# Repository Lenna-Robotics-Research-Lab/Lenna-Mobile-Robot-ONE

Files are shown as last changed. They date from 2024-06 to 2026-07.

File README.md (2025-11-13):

<div align="justify">

# Lenna Mobile Robot ONE
Lenna Autonomous Mobile Robot is designed for educational and research purposes. It is built upon a robust hardware architecture that combines an ARM-based embedded microcontroller and a Jetson Nano single-board computer (SBC) to provide both low-level and high-level control capabilities.

<div align="center">

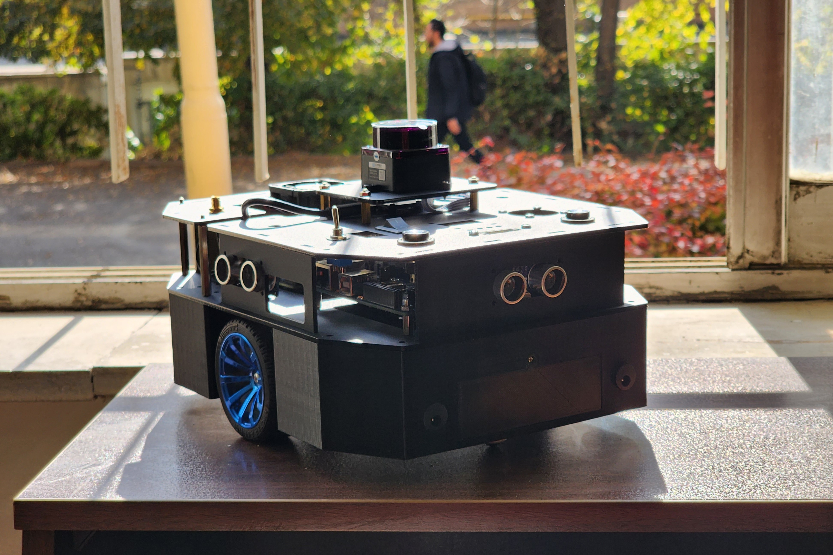
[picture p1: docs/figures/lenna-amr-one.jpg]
Lenna Mobile Robot ONE v.1.0.0
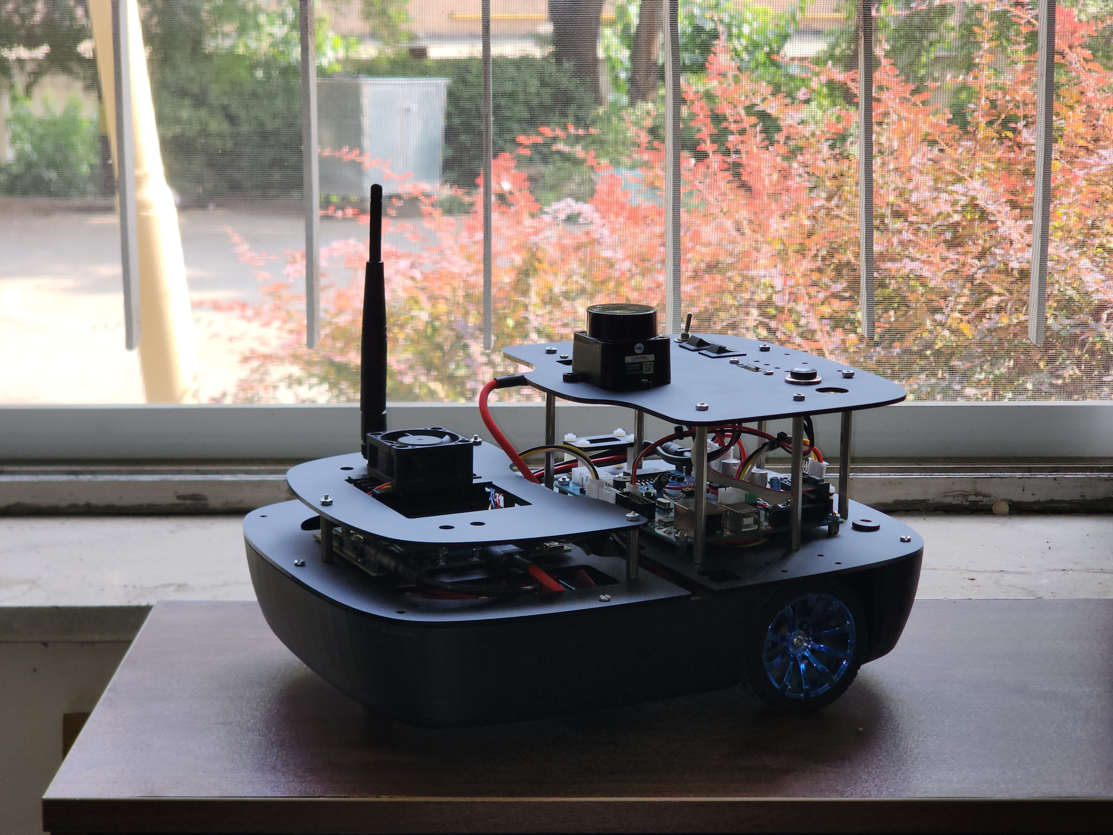
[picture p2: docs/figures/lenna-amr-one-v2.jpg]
Lenna Mobile Robot ONE v.2.0.0
|  |  |
|:--:|:--:|
| Lenna Mobile Robot ONE | LMRO Revised Model |

</div>

## Repository Structure

    .
    ├── hardware/                # Design & implementation
    │   ├── mechanics/           # CAD, 3D models, assembly instructions
    │   └── electronics/         # Schematics, PCB layouts, wiring
    │
    ├── software/
    │   ├── embedded/            # Microcontroller code (C/C++)
    │   └──  ros/                 # ROS packages, launch files, nodes
    │
    ├── docs/
    │   ├── user_manual/         # Setup, architecture, coding style
    │   └── figures/             # Images, diagrams, plots
    │
    └── README.md                # Entry point, quick start

## List of Contents
- [System Overview](#system-overview)
- [Mechanical Design](#mechanical-design)
- [Electronics Design](#electronics-design)
- [Control Architecture](#control-architecture)
- [Plug and Play](#plug-and-play)

## System Overview
The current design is a differential-drive Wheeled Mobile Robot (WMR) that employs a two-layer hierarchical
architecture consisting of a High-level Controller Board (HCB) and a Low-level Controller Board (LCB). The
HCB, which is either an Nvidia Jetson Nano B01 or an Nvidia Jetson Orin Nano depending on the target
ROS version, handles high-level processing, runs ROS, and interfaces with the Light Detection and Ranging
(LiDAR) sensor. The LCB is a custom-designed microcontroller-based embedded board built, responsible for
sensor interfacing and motor control. Communication between the two boards is established via Universal
Asynchronous Receiver/Transmitter (UART) serial communication and a custom protocol.

<div align="center">

| Physical Architecture |
|:--:| 
| LMRO Physical Architecture |
</div>

### Mechanical Design
In
this work, a differential drive mobile robot was developed following the unicycle kinematic model, which is
one of the most widely adopted models for wheeled robotic systems. The design process was carried out in
SolidWorks, with an emphasis on modularity, simplicity, and ease of future expansion. The proposed robot architecture follows a three-level stacked structure, where each layer hosts a distinct set of
components. This modular design allows rapid prototyping and straightforward replacement or modification
of subsystems without interfering with the core mechanical or electrical functionalities.

| Lenna Mobile Robot ONE v.2.0.0 |
|:--:| 
| LMRO Revised Model Exploded View and Components |

### Electronics Design
As mentioned earlier, the Lenna Robotics team has designed a custom PCB for the LCB, referred to as the
Bardia Board. The complete design is available on the Lenna Robotics GitHub page, and the following sections
provide details on the design choices, the considerations that shaped them, and the resulting component
selection.

<div align="center">

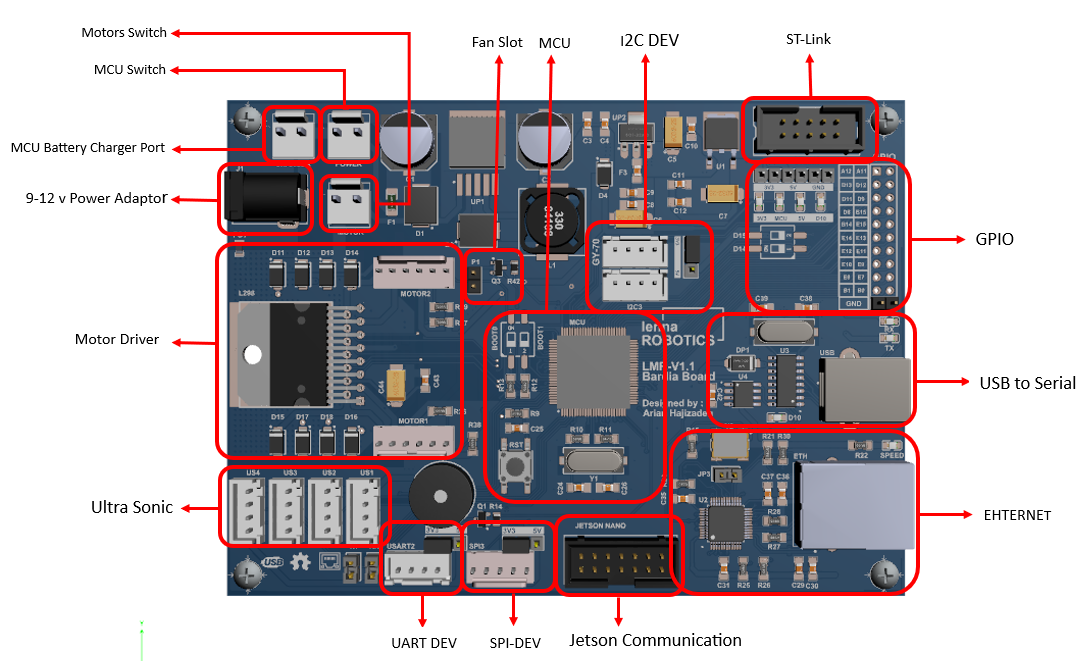
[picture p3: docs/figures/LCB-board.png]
electronics
|  |
|:--:| 
| LMRO Low-level Controller Board |

</div>

### Control Architecture
As previously mentioned, this robot employs a distributed architecture. In this architecture, robot control is
divided into two layers: the hardware control layer (LCB) and the robot control layer (HCB). The hardware
control layer is responsible for reading and filtering sensor data as well as controlling the motor dynamics. In contrast, the robot control layer handles more complex computations and high-level
decision-making. This hierarchical structure decouples the robot control from its governing dynamic equations and allows motion control to focus on kinematics at the velocity layer.
<div align="center">

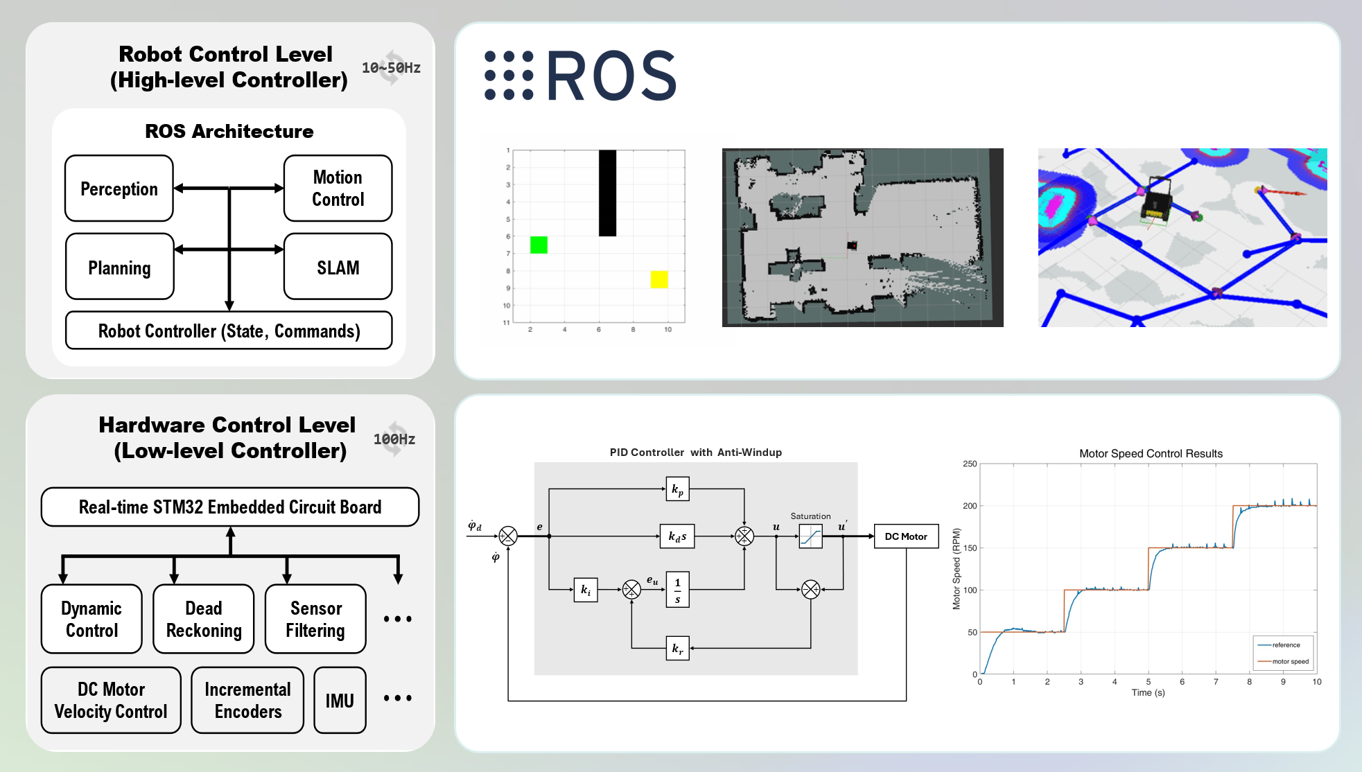
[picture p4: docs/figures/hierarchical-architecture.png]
control architecture
|  |
|:--:| 
| LMRO Hierarchical Control Architecture |

</div>

## Plug and Play
This section provides step-by-step procedures to create your own ROS workspace and run the nodes required to work with the **Lenna Mobile Robot (LMRO)**.

Always source your ROS distribution:

```bash
source /opt/ros/<distro>/setup.bash
```

Create your ROS workspace and add the mentioned lenna packages to the `/src` directory:

```bash
mkdir -p ~/lenna_ws/src
cd ~/lenna_ws
catkin build
```

Source the compiled workspace:

```bash
source ~/lenna_ws/devel/setup.bash
```

### Teleoperation
You can use the ROS package `teleop_twist_keyboard` to control LMRO using the `lenna_teleop_keyboard` launch file inside the `lenna_bringup` package:

```bash
roslaunch lenna_bringup lenna_teleop_keyboard.launch
```

### SLAM
Both `slam_toolbox` and `hector_slam` can be used for LMRO:

```bash
roslaunch lenna_bringup lenna_slam_toolbox.launch
```

or

```bash
roslaunch lenna_bringup lenna_slam_hector.launch
```

### Navigation
Using the `lenna_navigation_stack` launch file, you can use the ROS NavStack (`move_base` and `amcl` packages) to implement autonomous navigation:

```bash
roslaunch lenna_bringup lenna_navigation_stack.launch
```

## Citation
If you use this code or build upon this work, please cite:

```bibtex
@INPROCEEDINGS{11213761,
  author={Riazati, Erfan and Hajizadeh, Arian and Esmaeilzadeh, Seyed Majid},
  booktitle={2025 33rd International Conference on Electrical Engineering (ICEE)}, 
  title={Design and Implementation of a Modular ROS-Based Mobile Robot with Hierarchical Control}, 
  year={2025},
  volume={},
  number={},
  pages={1038-1043},
  keywords={Visualization;Simultaneous localization and mapping;Navigation;Computer architecture;Real-time systems;Hardware;Mobile robots;Synchronization;Tuning;Testing;mobile robot;hierarchical control;distributed control;navigation;SLAM;ROS},
  doi={10.1109/ICEE67339.2025.11213761}}

```

</div>

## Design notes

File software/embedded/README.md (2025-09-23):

# Lenna Mobile Robot ONE - Embedded Software
This embedded software is the low-level control system for the **Lenna Mobile Robot ONE**, a differential drive robot. It runs on an **STM32F407VGTX** microcontroller and is responsible for interfacing with all the onboard hardware, executing motion commands, and providing sensor feedback to a higher-level control system (e.g., a computer running ROS).

The core functionalities of this software include:
-   **Motor Control**: Precise control of the two DC motors using a PID (Proportional-Integral-Derivative) controller to achieve desired velocities.
-   **Odometry**: Reading data from wheel encoders to calculate the robot's position and orientation (pose).
-   **Sensor Fusion**: Interfacing with an Inertial Measurement Unit (IMU), specifically the MPU-6050 (accelerometer and gyroscope) and HMC5883L (magnetometer), and using a complementary filter to get a stable orientation estimate.
-   **Obstacle Avoidance**: Reading data from HC-SR04 ultrasonic sensors to detect obstacles in the robot's path.
-   **Communication**: Handling a custom serial communication protocol to receive velocity commands and send sensor data packets to a host computer.

## Dependencies

This project relies on the following libraries and modules:

-   **STM32F4xx HAL Library**: The primary dependency for this project. The Hardware Abstraction Layer (HAL) provided by STMicroelectronics is used for all low-level hardware interactions, including GPIO, I2C, UART, SPI, TIM (timers), and ADC peripherals.
-   **CMSIS (Cortex Microcontroller Software Interface Standard)**: This library is used for basic access to the ARM Cortex-M4 processor core features.
-   **C Standard Libraries**:
    -   `stdio.h`: For standard input/output functions.
    -   `stdlib.h`: For general utility functions.
    -   `stdbool.h`: For boolean type and values.
    -   `math.h`: For mathematical functions like `sqrtf` and `atan2f`.
    -   `string.h`: For memory manipulation functions like `memset`.

## Coding Convention

The code follows a structured and well-documented convention to ensure readability and maintainability.

-   **File and Module Structure**: Each distinct piece of functionality (e.g., motion, PID, odometry) is separated into its own module with a corresponding `.h` (header) and `.c` (source) file.
-   **Naming Convention**:
    -   **Functions**: All public functions are prefixed with `LRL_` (for Lenna Robotics Laboratory), followed by the module name, and then the function name in CamelCase (e.g., `LRL_Motion_MotorSpeed`).
    -   **Structures and Typedefs**: Custom data types generally end with `_cfgType` for configuration structures or `_statetype` for state-holding structures (e.g., `motor_cfgType`, `imu_statetype`).
    -   **Constants and Macros**: All constants and macros are defined in uppercase with underscores separating words (e.g., `MAX_PACKET_LENGTH`).
-   **Commenting**: The code is extensively commented using a **Doxygen-compatible** style. Each file and function has a header comment block explaining its purpose, author, date, parameters (`@param`), and return values (`@return`). This allows for automatic documentation generation.
-   **Code Style**:
    -   The code maintains a consistent indentation style.
    -   Function and variable names are descriptive.
    -   Private functions, intended for use only within their own module, are sometimes prefixed with an underscore (e.g., `_LRL_IMU_MPUBypassEn`).
-   **Configuration**: All hardware-related pin definitions and magic numbers are centralized in `mcu_config.h` and `main.h` to make it easier to adapt the code to different hardware configurations.

## Module Deep Dive

### Motion Control (`motion.c`/`motion.h`)

This module is responsible for the direct control of the robot's motors.

* **Key Data Structures**:
    * `motor_cfgType`: This structure holds the hardware configuration for a single motor, including GPIO pins for direction control and the timer handle and channel for PWM signal generation.
    * `diffDrive_cfgType`: This structure defines the entire differential drive robot, combining two `motor_cfgType` structures (one for the left motor and one for the right) and storing the robot's physical parameters, such as wheel radius and the distance between the wheels.

* **Main Functions**:
    * `LRL_Motion_MotorSpeed(motor_cfgType motor, int8_t duty_cycle)`: Sets the speed and direction of a single motor. A positive `duty_cycle` value drives the motor forward, while a negative value drives it backward. The magnitude of the `duty_cycle` (from -100 to 100) determines the motor's speed.
    * `LRL_Motion_Control(diffDrive_cfgType diffRobot, int8_t duty_cycle_left, int8_t duty_cycle_right)`: A higher-level function that controls both motors of the robot simultaneously, allowing for differential drive maneuvers like turning and moving in arcs.
    * `LRL_Motion_MotorTest(diffDrive_cfgType diffRobot)`: A utility function to run a pre-defined sequence of movements (e.g., forward, backward, pivot turns) to test the functionality of the motors and encoders.

---
### PID Controller (`pid.c`/`pid.h`)

This module implements a Proportional-Integral-Derivative (PID) controller for precise, closed-loop speed control of the motors.

* **Key Data Structures**:
    * `pid_cfgType`: This is the core structure for the PID controller. It stores the controller's gains (`Kp`, `Ki`, `Kd`), the sampling time (`Ts`), saturation limits for the output signal, and internal state variables like the accumulated integral amount and the previous measurement error. It also includes a flag to enable or disable an anti-windup feature.

* **Main Functions**:
    * `LRL_PID_Init(pid_cfgType *pid_cfg, uint8_t AntiWindup)`: Initializes the PID controller's state variables to zero and sets the anti-windup configuration.
    * `LRL_PID_Update(pid_cfgType *pid_cfg, int16_t measurement, int16_t set_point)`: This function is the heart of the PID controller. It calculates the error between the desired `set_point` and the current `measurement` (e.g., motor speed from odometry), computes the proportional, integral, and derivative terms, and generates a new control signal. It also handles output saturation and the anti-windup mechanism to prevent the integral term from accumulating excessively when the output is saturated.

---
### Odometry (`odometry.c`/`odometry.h`)

This module is responsible for tracking the robot's movement by reading data from the wheel encoders.

* **Key Data Structures**:
    * `encoder_cfgType`: Holds the configuration and state for a single wheel encoder, including a pointer to the hardware timer used in encoder mode, the timer's maximum count value (`MAX_ARR`), a conversion factor from ticks to RPM (`TICK2RPM`), and the current and previous tick counts.
    * `odom_cfgType`: The main odometry structure that combines two `encoder_cfgType` instances (for the right and left wheels), the robot's physical configuration (`diffDrive_cfgType`), and the calculated wheel velocities and incremental distances.

* **Main Functions**:
    * `LRL_Odometry_Init(odom_cfgType *odom)`: Initializes the odometry system by resetting the hardware encoder counters and clearing the software tick history.
    * `LRL_Odometry_ReadAngularSpeed(odom_cfgType *odom)`: This function performs the core odometry calculations. It reads the current raw tick counts from the encoder timers, calculates the difference in ticks since the last call (handling timer overflows), and converts this difference into physically meaningful units: angular velocity (in RPM) and the incremental distance traveled by each wheel.

---
### IMU and Magnetometer (`imu.c`/`imu.h`)

This module interfaces with the MPU-6050 Inertial Measurement Unit (IMU) and the HMC5883L magnetometer to determine the robot's orientation in space.

* **Key Data Structures**:
    * `imu_statetype`: The main state structure that holds all IMU-related data. This includes the I2C handle for communication, calibration offsets for the accelerometer, gyroscope, and magnetometer, and the latest sensor readings (raw and filtered).
    * The file also defines several helper structs like `linear_position`, `angular_position`, `accelerometer`, `gyroscope`, and `magnetometer` to organize the sensor data.

* **Main Functions**:
    * `LRL_IMU_MPUInit(imu_statetype * imu)`: Initializes the MPU-6050 sensor, configuring its power management, data rate, and measurement ranges. It also performs a calibration routine to determine the zero-rate offsets for the accelerometer and gyroscope.
    * `LRL_IMU_MagInit(imu_statetype * imu)`: Initializes the HMC5883L magnetometer, which is connected through the MPU-6050's auxiliary I2C bus. This function also calibrates the magnetometer's heading.
    * `LRL_IMU_MPUReadAll(imu_statetype *imu)`: A convenience function that reads the latest data from both the accelerometer and gyroscope.
    * `LRL_IMU_ComplementaryFilter(imu_statetype *imu, float dt)`: This is the sensor fusion algorithm. It combines the orientation data from the accelerometer (which is reliable in the long term but noisy) and the gyroscope (which is reliable in the short term but drifts over time) to produce a stable and accurate estimate of the robot's roll, pitch, and yaw angles.

---
### Packet Handler (`packet_handler.c`/`packet_handler.h`)

This module manages the serial communication protocol between the microcontroller and a host computer.

* **Key Data Structures**:
    * `packet_cfgType`: Stores the configuration and state for the packet handler, including a pointer to the UART handle, the minimum and maximum packet lengths, flags to indicate data validity, and a buffer for incoming and outgoing data.

* **Main Functions**:
    * `LRL_Packet_Handshake(packet_cfgType *packet)`: Establishes a connection with the host computer by repeatedly sending a signature and waiting for a specific acknowledgment. This ensures that both the robot and the host are ready for communication.
    * `LRL_Packet_TX(packet_cfgType *packet, odom_cfgType *odom, imu_statetype *imu)`: Assembles a data packet containing the latest sensor and odometry information (wheel velocities, distances, accelerometer data, gyroscope data, and orientation angles). It then calculates a CRC checksum for data integrity and transmits the packet via UART.
    * `LRL_Packet_RX(packet_cfgType *packet)`: Handles incoming data packets from the host. It reads the packet from the UART buffer, validates its integrity by checking the CRC, and if the packet is valid, it extracts the velocity commands for the left and right wheels.

---
### Ultrasonic Sensor (`ultrasonic.c`/`ultrasonic.h`)

This module provides an interface for the HC-SR04 ultrasonic distance sensors.

* **Key Data Structures**:
    * `ultrasonic_cfgType`: Holds the hardware configuration for a single ultrasonic sensor, including the GPIO pin for the trigger signal and the timer configuration (handle, instance, and channel) for measuring the echo pulse duration using the input capture feature.

* **Main Functions**:
    * `LRL_US_Init(ultrasonic_cfgType us)`: Initializes the timer and input capture interrupts for a given ultrasonic sensor.
    * `LRL_US_Trig(ultrasonic_cfgType us)`: Sends a short trigger pulse to the ultrasonic sensor to initiate a distance measurement.
    * `LRL_US_TMR_IC_ISR(TIM_HandleTypeDef *htim, ultrasonic_cfgType us)`: This is the interrupt service routine for the timer's input capture. It measures the time between the rising and falling edges of the echo pulse to calculate the distance to an object.
    * `LRL_US_Read(ultrasonic_cfgType us)`: Returns the last measured distance in centimeters.

---
### Utilities (`utilities.c`/`utilities.h`)

This module contains miscellaneous helper functions.

* **Main Functions**:
    * `LRL_Delay_Us(volatile uint16_t delay_us)`: Provides a blocking delay with microsecond-level precision, implemented using one of the microcontroller's hardware timers. This is useful for timing-critical operations like generating the trigger pulse for the ultrasonic sensor.

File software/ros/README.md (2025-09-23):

<div align="justify">

## ROS Workspace

    Catkin Workspace Directory  
    ├── src/  
    │   ├── lenna_bringup/  
    │   │   ├── scripts/  
    │   │   │   ├── serial_odom_node.py  
    │   │   │   ├── serial_cmd_node.py  
    │   │   │   └── ...  
    │   │   ├── launch/  
    │   │   │   ├── lenna_bringup.launch  
    │   │   │   └── ...  
    │   │   ├── config/  
    │   │   ├── rviz/  
    │   │   ├── maps/  
    │   │   ├── CMakeLists.txt  
    │   │   └── package.xml  
    │   ├── lenna_description/  
    │   ├── lenna_msgs/  
    │   └── ldlidar_stl_ros/  
    │
    ├── devel/  
    │   ├── setup.bash/  
    │   └── ...  
    │
    ├── build/  
    └── logs/  

</div>

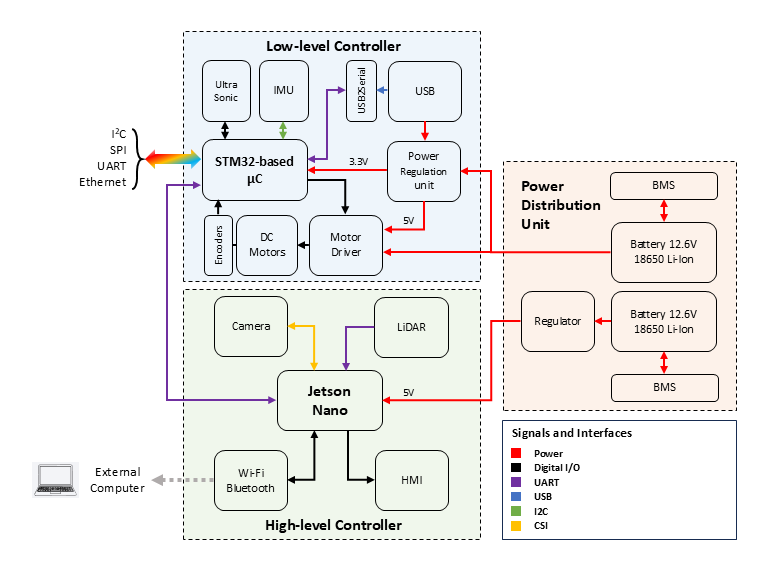
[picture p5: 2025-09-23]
docs/figures/physical_architecture.png

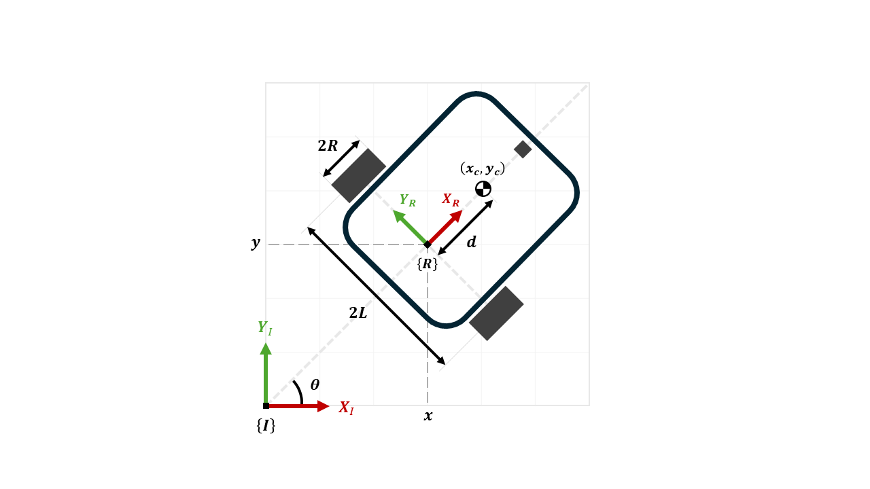
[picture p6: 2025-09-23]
docs/figures/ddrive-coordinate.png

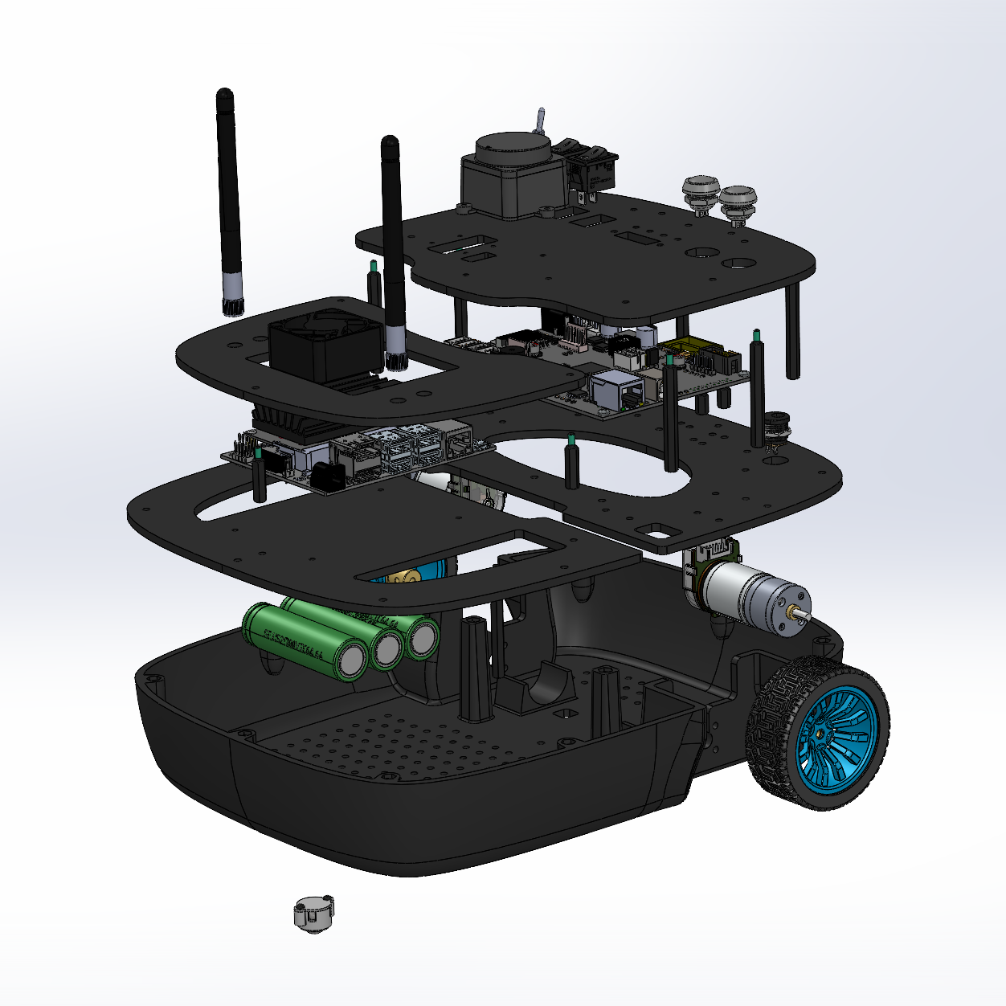
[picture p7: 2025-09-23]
docs/figures/exploded_view_v2_lmro.png

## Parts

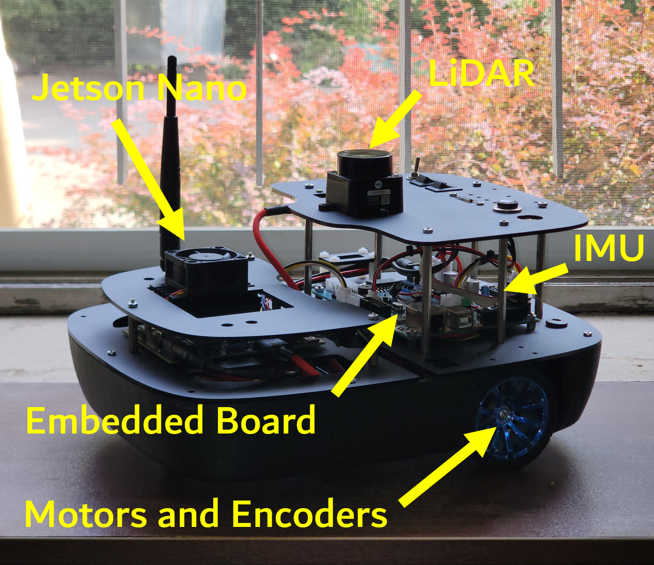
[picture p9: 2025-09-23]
docs/figures/Robot-Components.png

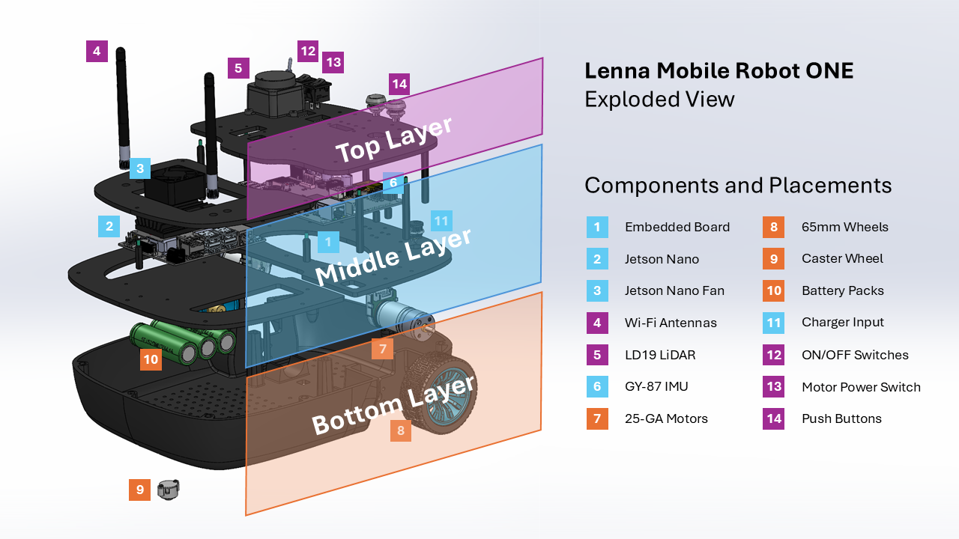
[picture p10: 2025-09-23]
docs/figures/exploded-components.png

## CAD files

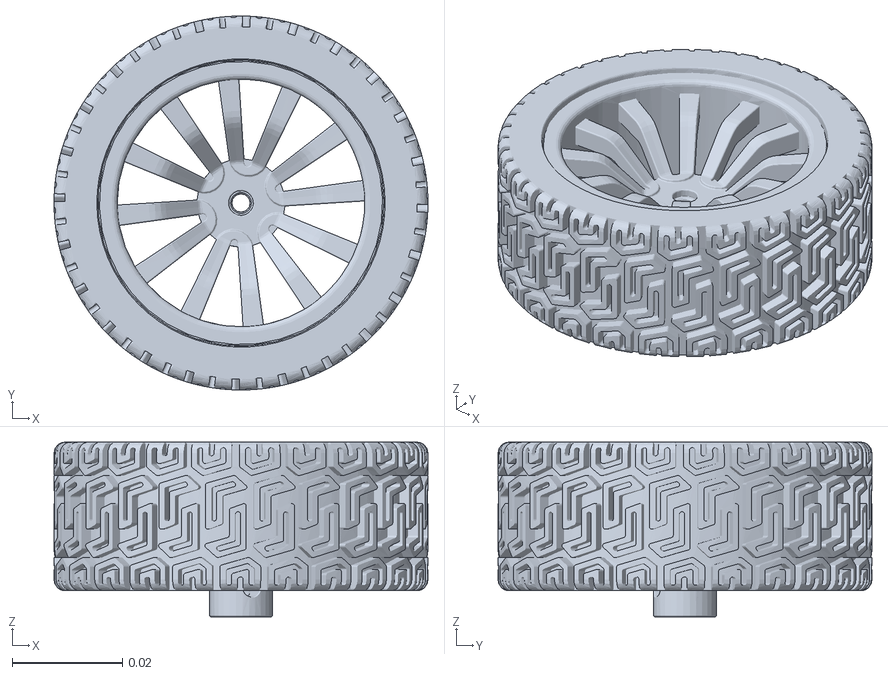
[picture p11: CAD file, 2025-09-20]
software/ros/lenna_description/meshes/left_wheel_link.STL
0.068 x 0.068 x 0.0317

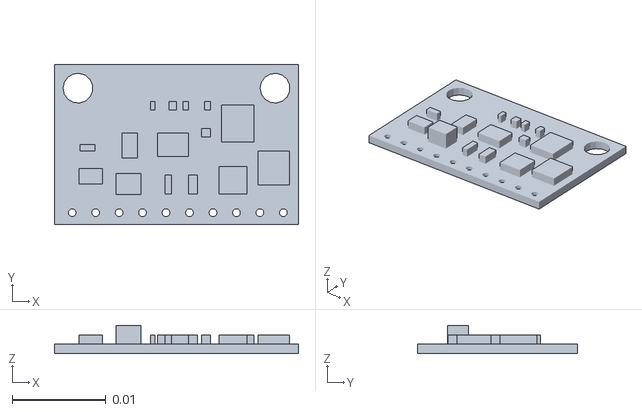
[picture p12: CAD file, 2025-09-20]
software/ros/lenna_description/meshes/inertial_sensor_link.STL
0.026 x 0.017 x 0.003

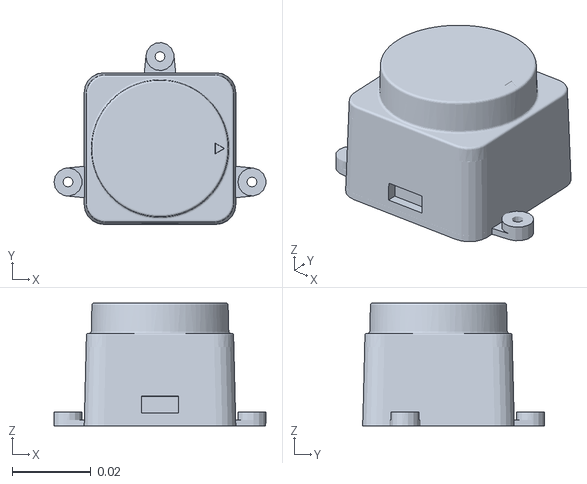
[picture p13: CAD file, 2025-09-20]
software/ros/lenna_description/meshes/laser_scanner_link.STL
0.054 x 0.0463 x 0.0313

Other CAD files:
software/ros/lenna_description/meshes/right_wheel_link.STL

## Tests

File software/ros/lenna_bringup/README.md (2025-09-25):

<div align="justify">

# lenna_bringup
The `lenna_bringup` package is responsible for handling all hardware-specific drivers for the **Lenna Mobile Robot**. It opens a serial port to establish communication with Lenna’s low-level controller boards.

This package isolates hardware interaction nodes from the high-level control nodes that are responsible for robot control algorithms (e.g., SLAM, navigation, path planning, etc.). It must be launched before any other program, since it initializes all the low-level nodes required for reliable communication with the robot hardware.

### Key Components
**Serial Communication Drivers:** Handle data exchange between the onboard computer and the robot’s microcontrollers.

**Packet and Frame Management Libraries:** Ensure structured communication, data integrity, and synchronization.

**ROS Nodes:** 
- Publish odometry data from the robot.
- Subscribe to velocity commands and transmit them to the robot’s actuators.
- Broadcast `odom` → `base_link` ROS Transform

By running this package first, all higher-level functionalities such as mapping, navigation, and path planning can operate seamlessly on top of the established hardware communication layer.

## Package Structure

    lenna_bringup/  
    ├── scripts/  
    │   ├── serial_handshake_node.py  
    │   ├── serial_odom_node.py 
    │   ├── serial_cmd_node.py 
    │   ├── field_ops.py 
    │   ├── serial_handler.py
    │   ├── packet_handler.py
    │   └── lenna_mobile_robot.py
    │
    ├── launch/  
    │   ├── lenna_bringup.launch
    │   ├── lenna_teleop_keyboard.launch
    │   ├── lenna_slam_toolbox.launch
    │   ├── lenna_slam_hector.launch  
    │   └── lenna_navigation_stack.launch  
    │
    ├── config/ 
    │   ├── costmap_common_params.yaml  
    │   └── ... 
    │
    ├── rviz/  
    ├── maps/  
    ├── CMakeLists.txt  
    └── package.xml 

## Dependancies
This package depends on the following ROS packages and tools:

### Core Build and Runtime Dependencies
- [catkin](http://wiki.ros.org/catkin) (build tool)
- [rospy](http://wiki.ros.org/rospy)
- [std_msgs](http://wiki.ros.org/std_msgs)
- [geometry_msgs](http://wiki.ros.org/geometry_msgs)
- [nav_msgs](http://wiki.ros.org/nav_msgs)
- [sensor_msgs](http://wiki.ros.org/sensor_msgs)

### Additional ROS Packages
- [teleop_twist_keyboard](http://wiki.ros.org/teleop_twist_keyboard)
- [slam_toolbox](http://wiki.ros.org/slam_toolbox)
- [hector_slam](http://wiki.ros.org/hector_slam)
- [navigation](http://wiki.ros.org/navigation) (Navigation Stack)

### Installation

Make sure your ROS environment is properly sourced, e.g.:

```bash
source /opt/ros/<distro>/setup.bash
```

Replace `distro` with your ROS distribution (e.g. `melodic`, `noetic`, etc.). For the presented Lenna Mobile Robot, the used ROS distribuition is melodic.

Run the following commands on terminal to install all dependencies:

```bash
$ sudo apt update
$ sudo apt install -y \
  ros-<distro>-rospy \
  ros-<distro>-std-msgs \
  ros-<distro>-geometry-msgs \
  ros-<distro>-nav-msgs \
  ros-<distro>-sensor-msgs \
  ros-<distro>-teleop-twist-keyboard \
  ros-<distro>-slam-toolbox \
  ros-<distro>-hector-slam \
  ros-<distro>-navigation
```

## List of Programs
- ROS Nodes
  - [serial_handshake_node.py](#serial_handshake_nodepy)
  - [serial_odom_node.py](#serial_odom_nodepy)
  - [serial_cmd_node.py](#serial_cmd_nodepy)
  - [odom_tf_broadcast.py](#odom_tf_broadcastpy)
- Custom Modules 
  - [field_ops.py](#field_opspy)
  - [serial_handler.py](#serial_handlerpy)
  - [packet_handler.py](#packet_handlerpy)
  - [lenna_mobile_robot.py](#lenna_mobile_robotpy)

---
# `field_ops.py`
Provides **utility functions and constants** for low-level communication and data handling in the Lenna mobile robot system. It defines protocol constants (communication results, instruction codes) and helper functions for working with **bytes, words, and signed integers**. This module is used by `PacketHandler`, `LennaMobileRobot`, and other communication-related components.

## Internal Structure

### Constants
- **Communication result codes**
  - `COMM_SUCCESS` – Transmission or reception success.  
  - `COMM_PORT_BUSY` – Serial port is busy.  
  - `COMM_TX_FAIL` – Failed to transmit packet.  
  - `COMM_RX_FAIL` – Failed to receive packet.  
  - `COMM_TX_ERROR` – Invalid transmission packet.  
  - `COMM_RX_WAITING` – Waiting for response packet.  
  - `COMM_RX_TIMEOUT` – Timeout waiting for response.  
  - `COMM_RX_CORRUPT` – Received corrupted packet.  
  - `COMM_NOT_AVAILABLE` – Function not available.  

- **Instruction codes**
  - `INST_MOTION_CONTROL = 0x01` – Instruction for motor motion control.  

### Functions
- **`combine2Word(a, b)`**  
  Combines two 16-bit integers into a 32-bit word.  

- **`combine2Byte(a, b)`**  
  Combines two 8-bit integers into a 16-bit word.  

- **`lowWord(l)`**  
  Extracts the low 16 bits from a 32-bit integer.  

- **`highWord(l)`**  
  Extracts the high 16 bits from a 32-bit integer.  

- **`lowByte(w)`**  
  Extracts the low 8 bits from a 16-bit integer.  

- **`highByte(w)`**  
  Extracts the high 8 bits from a 16-bit integer.  

- **`getSigned(nums)`**  
  Converts a list of 16-bit unsigned integers into signed integers (two’s complement).  

## Dependencies
This module uses **only the Python standard library** (no external dependencies).  

## ROS Interfaces
This file is **not a ROS node**.  
It is a **pure utility module** used by:  
- `PacketHandler` (for protocol packet construction/parsing).  
- `LennaMobileRobot` (for interpreting odometry and sensor data).  

---
# `serial_handler.py`
A Python class that manages **low-level serial communication** for the Lenna mobile robot. It provides methods to configure the serial port, open/close it, read/write data, and handle communication timeouts. This module acts as a hardware abstraction layer, enabling higher-level classes (e.g., `PacketHandler`, `LennaMobileRobot`) to interact with the robot’s microcontroller over UART.

## Internal Structure

### Class: `SerialHandler`
Encapsulates serial communication setup and I/O operations.

#### Attributes:
- **Connection state**  
  - `is_open` – Flag indicating if port is open.  
  - `is_using` – Flag indicating if port is currently in use.  

- **Port configuration**  
  - `port_name` – Serial device name (default: `/dev/ttyTHS1`).  
  - `baudrate` – Communication baudrate (default: `115200`).  
  - `parity`, `stopbits`, `bytesize`, `timeout` – Serial port parameters (default: 8N1, non-blocking).  

- **Serial port object**  
  - `ser` – `serial.Serial` object (PySerial instance).  

- **Timing control**  
  - `packet_start_time` – Timestamp when packet transmission started.  
  - `packet_timeout` – Allowed timeout for the packet.  
  - `tx_time_per_byte` – Estimated transmission time per byte (depends on baudrate).  

#### Functions:
- **`__init__(self, port_name='/dev/ttyTHS1', baudrate=115200)`**  
  Constructor. Initializes serial port parameters but does not open the port.  

- **`openPort(self)`**  
  Opens the port using the current baudrate.  

- **`closePort(self)`**  
  Closes the port and marks it as not open.  

- **`clearPort(self)`**  
  Flushes the serial port buffer.  

- **`setupPort(self)`**  
  Initializes and configures the serial port with stored parameters.  

- **`setPortName(self, port_name)` / `getPortName(self)`**  
  Set or retrieve the serial device name.  

- **`setBaudrate(self, baudrate)` / `getBaudRate(self)`**  
  Configures the baudrate (only if it is supported by the platform).  

- **`getBytesAvailable(self)`**  
  Returns number of bytes available in the input buffer.  

- **`readPort(self, length)`**  
  Reads `length` bytes from the port.  

- **`writePort(self, packet)`**  
  Writes a packet (byte array) to the port.  

- **`setPacketTimeout(self, packet_length, latency_timer=16)`**  
  Sets a timeout for a packet based on its length, baudrate, and latency.  

- **`setPacketTimeoutMillis(self, msec)`**  
  Sets a fixed timeout in milliseconds.  

- **`isPacketTimeout(self)`**  
  Checks if the packet timeout has expired.  

- **`getCurrentTime(self)`**  
  Returns current time in milliseconds.  

- **`getTimeSinceStart(self)`**  
  Returns elapsed time since `packet_start_time`.  

## Dependencies
This code depends on:  

- **External Python libraries**  
  - `time` (standard library)  
  - `serial` (PySerial library for serial communication)  

- **Hardware requirements**  
  - Serial device (e.g., `/dev/ttyTHS1` on Jetson Nano or similar).  

## ROS Interfaces
This class is **not a ROS node**.  
It is a **low-level utility module** used by:  
- `PacketHandler` (for protocol-level communication).  
- Higher-level robot ROS nodes (`SerialCmdVelNode`, `SerialOdomNode`).  

---
# `packet_handler.py`
َ Python class that implements a **custom serial communication protocol (v0.0.1)** for the Lenna mobile robot.  It handles low-level packet creation, transmission, reception, and validation using CRC16. This module is a core component for communicating with the robot’s onboard microcontroller and is used by higher-level classes (e.g., `LennaMobileRobot`).

## Internal Structure

### Constants
- **Packet format fields**  
  - `PKT_HEADER0 = 0` – First header byte (0xFF).  
  - `PKT_HEADER1 = 1` – Second header byte (0xFF).  
  - `PKT_LENGTH = 2` – Length of packet.  
  - `PKT_INSTRUCTION = 3` – Instruction code.  
  - `PKT_PARAMETER_H = 4` – High byte of first parameter.  
  - `PKT_PARAMETER_L = 5` – Low byte of first parameter.  
  - `PKT_CRC_H = 6` – CRC16 high byte.  
  - `PKT_CRC_L = 7` – CRC16 low byte.  

- **Packet size constraints**  
  - `MIN_LEN_PACKET = 8` – Minimum packet size.  
  - `TXPACKET_MAX_LEN = 144` – Maximum transmit packet size.  
  - `RXPACKET_MAX_LEN = 144` – Maximum receive packet size.  

### Class: `PacketHandler`
Encapsulates communication protocol logic.

#### Functions:
- **`__init__(self, port)`**  
  Initializes the handler with a given serial port object (`port`).  

- **`getProtocolVersion(self)`**  
  Returns the protocol version string (`"v0.0.1"`).  

- **`updateCRC(self, crc_accum, data_blk_ptr, data_blk_size)`**  
  Calculates and updates the CRC16 checksum for a packet.  

- **`txPacket(self, instruction, parameters)`**  
  Builds and transmits a packet with a given instruction and parameter list.  
  - Adds headers, instruction code, parameters, and CRC16.  
  - Writes packet to the serial port.  
  - Returns communication status (`COMM_SUCCESS`, `COMM_TX_FAIL`, etc.).  

- **`rxPacket(self, timeout=100)`**  
  Reads a packet from the serial port.  
  - Waits until data is available or timeout expires.  
  - Returns `(rxpacket, rxlength, result)` where:  
    - `rxpacket` – received packet (list of bytes).  
    - `rxlength` – length of received data.  
    - `result` – communication result (`COMM_SUCCESS`, `COMM_RX_FAIL`, etc.).  

## Dependencies
This code depends on:  

- **External Python libraries**  
  - `time`  

- **Custom modules**  
  - `field_ops` (provides `highByte`, `lowByte`, and communication constants like `COMM_SUCCESS`, `COMM_RX_FAIL`, etc.)  

- **Hardware/Driver requirements**  
  - A serial port object (`port`) with methods:  
    - `is_using` (flag for port usage)  
    - `clearPort()`  
    - `writePort(packet)`  
    - `readPort(length)`  
    - `getBytesAvailable()`  
    - `getCurrentTime()`  

## ROS Interfaces
This class is **not a ROS node**.  
It is a **backend communication utility**, typically used by:  
- `LennaMobileRobot` (for motion control & odometry).  
- Higher-level ROS nodes (`SerialOdomNode`, `SerialCmdVelNode`).  

---
# `lenna_mobile_robot.py`
A Python helper class that provides a high-level interface to the **Lenna mobile robot**. It wraps low-level serial communication protocols to control motor speeds, retrieve odometry, and perform orientation conversions. This class is used by higher-level ROS nodes (e.g., `SerialCmdVelNode`, `SerialOdomNode`) to interact with the robot.

## Internal Structure

### Class: `LennaMobileRobot`
Encapsulates robot hardware control and odometry parsing.

#### Functions:
- **`__init__(self, protocol)`**  
  Initializes the robot with a communication protocol (e.g., `PacketHandler`).  

- **`rpy2quat(self, roll, pitch, yaw)`**  
  Converts Euler angles (roll, pitch, yaw in radians) into a quaternion `[x, y, z, w]`.  

- **`setMotorSpeed(self, motor_speed_left, motor_speed_right)`**  
  Sends left and right motor speeds (in RPM) to the robot using the motion control instruction.  

- **`getOdometry(self, timeout=100)`**  
  Requests odometry data from the robot. Returns:  
  - Left & right wheel speeds (RPM).  
  - Left & right wheel distances.  
  - Accelerometer readings (`acc_x`, `acc_y`, `acc_z`).  
  - Gyroscope readings (`gyro_x`, `gyro_y`, `gyro_z`).  
  - Orientation (`roll`, `pitch`, `yaw`).  
  Along with the packet length and communication status (`result`).  

#### Main Variables:
  - `odometry_length = 32` – expected odometry packet size.  
  - `min_motor_speed = 0` – minimum motor speed (RPM).  
  - `max_motor_speed = 250` – maximum motor speed (RPM).  
  - `wheel_radius = 0.0325` m – radius of each wheel.  
  - `wheel_distance = 0.19` m – distance between wheels.  

## Dependencies
This code depends on the following libraries and modules:  

- **External Python libraries**  
  - `numpy`  

- **Custom modules**  
  - `packet_handler`  
  - `field_ops`  

## ROS Interfaces
This class is **not a ROS node**.  
It serves as a backend utility and is used by other ROS nodes such as:  
- `SerialOdomNode` (for odometry parsing).  
- `SerialCmdVelNode` (for motor control).  

---
# `serial_handshake_node.py`
A ROS node responsible for establishing communication over a serial connection. It listens for a predefined handshake keyword from the robot, sends back a confirmation byte if successful, and publishes the handshake status as a `std_msgs/Bool` message on the `/handshake` topic. Other nodes (e.g., odometry publishers and cmd_vel subscribers) rely on this handshake to ensure the robot is ready before operation.

## Internal Structure

### Class: `SerialHandshakeNode`
Main class that encapsulates the handshake logic.

#### Functions:
- **`__init__(self)`**  
  Initializes ROS parameters, serial handler, packet handler, ROS node, and publisher.  

- **`handle_handshake(self)`**  
  Main loop for handshake handling:  
  - Reads serial data with a timeout of 5 seconds.  
  - Verifies the handshake keyword.  
  - Sends confirmation byte if valid.  
  - Publishes handshake status (`True`/`False`).  

#### Main Variables:
- `flag` – indicates whether handshake is completed (`True`) or pending (`False`).  

## Dependencies
This code depends on the following libraries and modules:  

- **ROS Python libraries**  
  - `rospy`  
  - `std_msgs.msg` (`Bool`)  

- **External Python libraries**  
  - `serial`  
  - `time`  

- **Custom modules**  
  - `serial_handler.SerialHandler`  
  - `packet_handler.PacketHandler`  

## ROS Interfaces

### Node
- **Name:** `node_handshake`  

### Published Topics
- **`/handshake`** (`std_msgs/Bool`)  
  - `False`: handshake attempt in progress or failed.  
  - `True`: handshake successfully completed.  

### Subscribed Topics
- *(None)*  

### Parameters
- `~port` (`string`, default `/dev/ttyTHS1`) – serial port of the robot.  
- `~baudrate` (`int`, default `115200`) – baud rate for serial communication.  

---
# `serial_odom_node.py`
A ROS node that reads wheel encoder data via a serial connection and publishes the robot’s odometry as a `nav_msgs/Odometry` message. It performs **dead reckoning** to estimate the robot’s pose (`x`, `y`, `theta`) and velocity (`v`, `w`), and broadcasts this information to other ROS components. A handshake mechanism is used to ensure proper initialization before odometry data is published.

## Internal Structure

### Class: `SerialOdomNode`
Main class that encapsulates the ROS node.

#### Functions:
- **`__init__(self)`**  
  Initializes ROS parameters, serial communication, robot interface, publishers, and subscribers.  

- **`_init_odometry_msg(self) -> Odometry`**  
  Creates a default `Odometry` message with zero pose and velocity.  

- **`update_odom(self)`**  
  Updates the robot’s pose (`x`, `y`, `theta`) based on wheel encoder distances using dead reckoning.  

- **`handle_odometry(self)`**  
  Main loop: reads encoder values, computes odometry, updates the `Odometry` message, and publishes it.  

- **`handshake_callback(self, msg: Bool)`**  
  Callback function for `/handshake` topic. Ensures odometry publishing starts only after handshake is established.  

#### Main Variables: 
- `x, y, theta` – estimated robot pose.  
- `left_wheel_dist, right_wheel_dist` – encoder distances (mm → m).  
- `left_wheel_vel, right_wheel_vel` – wheel velocities (m/s).  
- `odom` – `nav_msgs/Odometry` message being published.  
- `handshake_established` – boolean flag for handshake state.  

## Dependencies
This code depends on the following libraries and modules:  

- **ROS Python libraries**  
  - `rospy`  
  - `nav_msgs.msg` (`Odometry`)  
  - `geometry_msgs.msg` (`Quaternion`)  
  - `std_msgs.msg` (`Bool`)  

- **External Python libraries**  
  - `numpy`  

- **Custom modules**  
  - `serial_handler.SerialHandler`  
  - `packet_handler.PacketHandler`  
  - `field_ops.getSigned`  
  - `lenna_mobile_robot.LennaMobileRobot`  

## ROS Interfaces

### Node
- **Name:** `node_serial_odom`  

### Subscribed Topics
- **`/handshake`** (`std_msgs/Bool`)  
  Used to establish or verify handshake with another node before publishing odometry.  

### Published Topics
- **`/odom`** (`nav_msgs/Odometry`)  
  Robot odometry including position, orientation, linear velocity, and angular velocity.  

### Parameters
- `~port` (`string`, default `/dev/ttyTHS1`) – serial port of the robot.  
- `~baudrate` (`int`, default `115200`) – baud rate for serial communication.  
- `~odom_tf_parent_frame` (`string`, default `odom`) – frame ID for odometry reference.  
- `~odom_tf_child_frame` (`string`, default `base_link`) – frame ID for robot base.  

---
# `serial_cmd_node.py`
A ROS node that listens to velocity commands (`geometry_msgs/Twist`) on the `/cmd_vel` topic and converts them into **motor commands** for the Lenna mobile robot. Using the robot’s kinematic model, it calculates left and right wheel speeds, converts them into RPM, clamps them to allowed motor limits, and sends the values over a serial connection. The node requires a successful handshake (from `/handshake`) before executing commands.

## Internal Structure

### Class: `SerialCmdVelNode`
Main class that encapsulates the ROS node.

#### Functions:
- **`__init__(self)`**  
  Initializes ROS parameters, serial communication, robot interface, and ROS publishers/subscribers.  

- **`twist_callback(self, msg: Twist)`**  
  Processes velocity commands from `/cmd_vel`:  
  - Converts linear and angular velocity into left/right motor speeds.  
  - Converts speeds from m/s to RPM.  
  - Clamps motor speeds to robot’s allowed range.  
  - Logs velocity information.  
  - Sends the motor commands via serial.  

- **`handshake_callback(self, msg: Bool)`**  
  Updates handshake status based on `/handshake` messages. Ensures that motor commands are only sent once the handshake is established.  

- **`spin(self)`**  
  Keeps the ROS node running with `rospy.spin()`.  

#### Main Variables:
- `linear, angular` – last commanded velocities.  
- `handshake_established` – flag indicating whether handshake has been completed.  

## Dependencies
This code depends on the following libraries and modules:  

- **ROS Python libraries**  
  - `rospy`  
  - `geometry_msgs.msg` (`Twist`)  
  - `std_msgs.msg` (`Bool`)  

- **External Python libraries**  
  - `numpy`  

- **Custom modules**  
  - `serial_handler.SerialHandler`  
  - `packet_handler.PacketHandler`  
  - `lenna_mobile_robot.LennaMobileRobot`  

## ROS Interfaces

### Node
- **Name:** `node_serial_cmd_vel`  

### Subscribed Topics
- **`/cmd_vel`** (`geometry_msgs/Twist`)  
  Desired robot velocity (linear and angular).  

- **`/handshake`** (`std_msgs/Bool`)  
  Handshake status from the handshake node.  

### Published Topics
- *(None)*  

### Parameters
- `~port` (`string`, default `/dev/ttyTHS1`) – serial port of the robot.  
- `~baudrate` (`int`, default `115200`) – baud rate for serial communication.  

---
# `odom_tf_broadcast.py`
A ROS node that listens to odometry data (`/odom`) and broadcasts the corresponding **TF transform** between two coordinate frames (default: `odom` → `base_link`). This allows other ROS nodes (e.g., navigation or visualization tools like RViz) to use the robot’s odometry as a transform tree in the ROS TF system.

## Internal Structure

### Class: `OdomTransformer`
Main class that encapsulates the ROS node.

#### Functions:
- **`__init__(self)`**  
  Initializes the ROS node, parameters, TF broadcaster, and odometry subscriber.  

- **`transformation_subscriber_callback(self, data: Odometry)`**  
  Callback function that processes incoming odometry data and converts it into a TF transform, which is then broadcast.  

- **`spin(self)`**  
  Keeps the node running and processing callbacks.  

### Function: `main()`  
Creates an instance of `OdomTransformer` and runs the node.  

#### Main Variables:
- `odom_trans` – stores the transform derived from odometry data.  

## Dependencies
This code depends on the following libraries and modules:  

- **ROS Python libraries**  
  - `rospy`  
  - `tf2_ros`  
  - `nav_msgs.msg` (`Odometry`)  
  - `geometry_msgs.msg` (`TransformStamped`)  

- **External Python libraries**  
  - *(None)*  

- **Custom modules**  
  - *(None)*  

## ROS Interfaces

### Node
- **Name:** `node_odom_transformer`  

### Subscribed Topics
- **`/odom`** (`nav_msgs/Odometry`)  
  Provides robot odometry data to be converted into TF transforms.  

### Published Topics
- *(None directly, but broadcasts TF transforms using `tf2_ros.TransformBroadcaster`)*  

### Parameters
- `~odom_tf_parent_frame` (`string`, default `odom`) – parent frame for transform.  
- `~odom_tf_child_frame` (`string`, default `base_link`) – child frame for transform.  

</div>

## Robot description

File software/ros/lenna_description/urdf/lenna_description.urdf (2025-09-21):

<?xml version="1.0" encoding="utf-8"?>
<robot name="lenna_description">

  <!-- <link name="world"/>
  <joint name="world_joint" type="fixed">
    <parent link="world"/>
    <child link="base_link"/>
    <origin rpy="0 0 0" xyz="0.0 0.0 0.02"/>
  </joint> -->

  <link name="base_link">
    <inertial>
      <origin xyz="0.0 0.0 0.0" rpy="0 0 0" />
      <mass value="2" />
      <inertia ixx="0.01" ixy="0.0" ixz="0.0" iyy="0.01" iyz="0.0" izz="0.5" />
    </inertial>
    <visual>
      <origin xyz="0 0 0" rpy="0 0 0" />
      <geometry>
        <mesh filename="package://lenna_description/meshes/base_link.STL" />
      </geometry>
      <material name="">
        <color rgba="0.12 0.12 0.12 1" />
      </material>
    </visual>
    <collision>
      <origin xyz="0 0 0" rpy="0 0 0" />
      <geometry>
        <mesh filename="package://lenna_description/meshes/base_link.STL" />
      </geometry>
    </collision>
  </link>
  <link name="right_wheel_link">
    <inertial>
      <origin xyz="0.0 0.0 0.0" rpy="0 0 0" />
      <mass value="0.05" />
      <inertia ixx="0.001" ixy="0.0" ixz="0.0" iyy="0.001" iyz="0.0" izz="0.001" />
    </inertial>
    <visual>
      <origin xyz="0 0 0" rpy="0 0 0" />
      <geometry>
        <mesh filename="package://lenna_description/meshes/right_wheel_link.STL" />
      </geometry>
      <material name="">
        <color rgba="0.075 0.075 0.075 1" />
      </material>
    </visual>
    <collision>
      <origin xyz="0 0 0" rpy="0 0 0" />
      <geometry>
        <mesh filename="package://lenna_description/meshes/right_wheel_link.STL" />
      </geometry>
    </collision>
  </link>
  <joint name="right_wheel_joint" type="continuous">
    <origin xyz="6.9033E-05 -0.08975 0.0150125" rpy="1.5708 0 0" />
    <parent link="base_link" />
    <child link="right_wheel_link" />
    <axis xyz="0 0 -1" />
    <limit effort="0.52" velocity="31" />
    <dynamics damping="0.01" friction="0.6" />
  </joint>
  <link name="left_wheel_link">
    <inertial>
      <origin xyz="0.0 0.0 0.0" rpy="0 0 0" />
      <mass value="0.05" />
      <inertia ixx="0.001" ixy="0.0" ixz="0.0" iyy="0.001" iyz="0.0" izz="0.001" />
    </inertial>
    <visual>
      <origin xyz="0 0 0" rpy="0 0 0" />
      <geometry>
        <mesh filename="package://lenna_description/meshes/left_wheel_link.STL" />
      </geometry>
      <material name="">
        <color rgba="0.075 0.075 0.075 1" />
      </material>
    </visual>
    <collision>
      <origin xyz="0 0 0" rpy="0 0 0" />
      <geometry>
        <mesh filename="package://lenna_description/meshes/left_wheel_link.STL" />
      </geometry>
    </collision>
  </link>
  <joint name="left_wheel_joint" type="continuous">
    <origin xyz="6.9033E-05 0.08975 0.0150125" rpy="-1.5708 0 0" />
    <parent link="base_link" />
    <child link="left_wheel_link" />
    <axis xyz="0 0 1" />
    <limit effort="0.52" velocity="31" />
    <dynamics damping="0.01" friction="0.6" />
  </joint>

  <link name="laser_scanner_link">
    <inertial>
      <origin xyz="0.0 0.0 0.0" rpy="0 0 0" />
      <mass value="0.05" />
      <inertia ixx="0.0001" ixy="0.0" ixz="0.0" iyy="0.0001" iyz="0.0" izz="0.0001" />
    </inertial>
    <visual>
      <origin xyz="0 0 0" rpy="0 0 0" />
      <geometry>
        <mesh filename="package://lenna_description/meshes/laser_scanner_link.STL" />
      </geometry>
      <material name="">
        <color rgba="0.08 0.08 0.08 1" />
      </material>
    </visual>
    <collision>
      <origin xyz="0 0 0" rpy="0 0 0" />
      <geometry>
        <mesh filename="package://lenna_description/meshes/laser_scanner_link.STL" />
      </geometry>
    </collision>
  </link>
  <joint name="laser_scanner_joint" type="fixed">
    <origin xyz="6.9033E-05 0 0.14644" rpy="0 0 0" />
    <parent link="base_link" />
    <child link="laser_scanner_link" />
    <axis xyz="0 0 0" />
  </joint>
  <link name="inertial_sensor_link">
    <inertial>
      <origin xyz="0.0 0.0 0.0" rpy="0 0 0" />
      <mass value="0.005" />
      <inertia ixx="0.00001" ixy="0.0" ixz="0.0" iyy="0.00001" iyz="0.0" izz="0.00001" />
    </inertial>
    <visual>
      <origin xyz="0 0 0" rpy="0 0 0" />
      <geometry>
        <mesh filename="package://lenna_description/meshes/inertial_sensor_link.STL" />
      </geometry>
      <material name="">
        <color rgba="0.08 0.08 0.08 1" />
      </material>
    </visual>
    <collision>
      <origin xyz="0 0 0" rpy="0 0 0" />
      <geometry>
        <mesh filename="package://lenna_description/meshes/inertial_sensor_link.STL" />
      </geometry>
    </collision>
  </link>
  <joint name="inertial_sensor_joint" type="fixed">
    <origin xyz="0.065091 -0.077436 0.064" rpy="0 0 0" />
    <parent link="base_link" />
    <child link="inertial_sensor_link" />
    <axis xyz="0 0 0" />
  </joint>

  <!--   JOINTS' TRANSMISSIONS AND ACTUATION   -->
  <transmission name="right_wheel_link_trans">
    <type>transmission_interface/SimpleTransmission</type>
    <joint name="right_wheel_joint">
      <hardwareInterface>hardware_interface/VelocityJointInterface</hardwareInterface>
    </joint>
    <actuator name="right_wheel_link_motor">
      <hardwareInterface>hardware_interface/VelocityJointInterface</hardwareInterface>
      <mechanicalReduction>1</mechanicalReduction>
    </actuator>
  </transmission>

  <transmission name="left_wheel_link_trans">
    <type>transmission_interface/SimpleTransmission</type>
    <joint name="left_wheel_joint">
      <hardwareInterface>hardware_interface/VelocityJointInterface</hardwareInterface>
    </joint>
    <actuator name="left_wheel_link_motor">
      <hardwareInterface>hardware_interface/VelocityJointInterface</hardwareInterface>
      <mechanicalReduction>1</mechanicalReduction>
    </actuator>
  </transmission>

  <!--   GAZEBO PLUGINS AND CONFIGURATIONS   -->
  <gazebo>
    <plugin name="gazebo_ros_control" filename="libgazebo_ros_control.so">
      <robotNamespace>/LENNA</robotNamespace>
    </plugin>
  </gazebo>

  <gazebo reference="right_wheel_link">
    <mu1 value="200.0"/>
    <mu2 value="100.0"/>
    <kp value="10000000.0" />
    <kd value="1.0" />
    <material>Gazebo/Grey</material>
  </gazebo>

  <gazebo reference="left_wheel_link">
    <mu1 value="200.0"/>
    <mu2 value="100.0"/>
    <kp value="10000000.0" />
    <kd value="1.0" />
    <material>Gazebo/Grey</material>
  </gazebo>
</robot>

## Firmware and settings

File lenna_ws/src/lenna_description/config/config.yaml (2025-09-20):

LENNA:
  right_wheel_joint_state_controller:
    type: joint_state_controller/JointStateController
    publish_rate: 20

  right_wheel_velocity_controller:
    type: velocity_controllers/JointVelocityController
    joint: right_wheel_joint
    pid: {p: 5.0, i: 0.1, d: 0.0005}

  left_wheel_joint_state_controller:
    type: joint_state_controller/JointStateController
    publish_rate: 20

  left_wheel_velocity_controller:
    type: velocity_controllers/JointVelocityController
    joint: left_wheel_joint
    pid: {p: 5.0, i: 0.1, d: 0.0005}

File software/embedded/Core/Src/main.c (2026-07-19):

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
/* Includes ------------------------------------------------------------------*/
#include "main.h"
#include "adc.h"
#include "eth.h"
#include "i2c.h"
#include "spi.h"
#include "tim.h"
#include "usart.h"
#include "gpio.h"

/* USER CODE BEGIN Includes */
#include "stdio.h"
#include "stdlib.h"
#include "stdbool.h"
#include "ultrasonic.h"
#include "utilities.h"
#include "motion.h"
#include "pid.h"
#include "math.h"
#include "odometry.h"
#include "mcu_config.h"
#include "imu.h"
#include "rosserial.h"



/* USER CODE END Includes */

/* USER CODE BEGIN PM */
#define PUTCHAR_PROTOTYPE int __io_putchar(int ch)

/* USER CODE END PM */


/* USER CODE BEGIN PV */

// message buffer for Initialization on High-level board
uint8_t msgBuffer[32] = " Lenna Robotics Research Lab. \r\n";

// Protocol packet size limits
uint8_t min_len_packet = 8;
uint8_t max_len_packet = 32;

//protocol Settings
//uint8_t protocol_data[144] = {0};
bool flag_uart_cb = 0;
bool flag_remain_packet = 1;

uint8_t total_pkt_length = 0;
uint8_t remain_pkt_length = 0;

unsigned short temp_crc = 0;

char MSG[64];

// LENNA for the ack
uint8_t txBuffer[144]; //= {0xFF, 0xFF, 0x05, 0xA0, 0xAB, 0xCD, 0xB4, 0xFC};



// step given by MATLAB code
uint8_t input_speed ;

// temp variables for odom
uint16_t left_enc_temp = 0, right_enc_temp = 0 , right_enc_diff = 0, left_enc_diff = 0;

// direction set
int8_t dir_right,dir_left;

//odom variables
uint16_t encoder_tick[2] = {0};
float angular_speed_left,angular_speed_right;
uint16_t tst;

uint8_t flag_tx = 0, pid_tim_flag = 0, dir_flag = 0;

uint8_t serial_flag = 0;


uint8_t test_flag = 0;


// ####################   Motor struct Value Setting   ###################
const motor_cfgType motor_right =
{
	MOTOR_PORT,
	MOTOR1_A_PIN,
	MOTOR_PORT,
	MOTOR1_B_PIN,
	&htim8,
	TIM_CHANNEL_1,
	1000,
	//1
};
const motor_cfgType motor_left =
{
	MOTOR_PORT,
	MOTOR2_A_PIN,
	MOTOR_PORT,
	MOTOR2_B_PIN,
	&htim8,
	TIM_CHANNEL_2,
	1000,
	//-1
};

// ####################   Ultra-Sonic struct Value Setting   ###################

const diffDrive_cfgType diff_robot =
{
	motor_right,
	motor_left,
	32.5,
	180
};

// ####################   ODOMETRY  ###################
const imu_cfgType gy87 =
{
	&hi2c3
};

const encoder_cfgType enc_right =
{
	&htim3,
	48960,
	0.1225f		// 6000/48960
};

const encoder_cfgType enc_left =
{
	&htim2,
	48960,
	0.1225f		// 6000/48960
};

odom_cfgType odom =
{
//	imu,
	enc_right,
	enc_left,
	diff_robot
};

imu_statetype imu =
{
	gy87
};

const ultrasonic_cfgType us_front =
{
	US1_TRIG_PORT,
	US1_TRIG_PIN,
	&htim4,
	TIM4,
	TIM_CHANNEL_3,
	168,
	1
};

// ####################   PID struct Value Setting   ###################

// definitions concerning PID gain values are made in the main.h header file
//pid_cfgType pid_motor_left =
//{
//	.Kp 					= Proportional_Gain_LEFT_MOTOR,
//	.Ki 					= Integral_Gain_LEFT_MOTOR,
//	.Kd 					= Derivative_Gain_LEFT_MOTOR,
//	.Ts 					= Sampling_Time,
//	.Lower_Limit_Saturation = Lower_Saturation_Limit,
//	.Upper_Limit_Saturation = Upper_Saturation_Limit,
//	.Wind_Up_Amount			= 1,
//};
//
//pid_cfgType pid_motor_right =
//{
//	.Kp 					= Proportional_Gain_LEFT_MOTOR,
//	.Ki 					= Integral_Gain_LEFT_MOTOR,
//	.Kd 					= Derivative_Gain_LEFT_MOTOR,
//	.Ts 					= Sampling_Time,
//	.Lower_Limit_Saturation = Lower_Saturation_Limit,
//	.Upper_Limit_Saturation = Upper_Saturation_Limit,
//	.Wind_Up_Amount			= 1,
//};

pid_cfgType mypid;
// ####################   Packet struct Value Setting   ###################


rosserial_cfgType ros_packet;
rosserial_cfgType usb2serial_packet;

int16_t val_x;
int16_t val_y;
int16_t val_z;
float val_heading;

uint8_t testBuffer[10]; // buffer for using test uart packet

//uint8_t protocol_buffer[256]; // the buffer used for the protocol

/* USER CODE END PV */

void SystemClock_Config(void);
/* USER CODE BEGIN 0 */

// ####################   UART Tx -> printf   ####################
PUTCHAR_PROTOTYPE
{
  /* Place your implementation of fputc here */
  /* e.g. write a character to the USART1 and Loop until the end of transmission */
  HAL_UART_Transmit(&huart1, (uint8_t *)&ch, 1, 0xFFFF);

  return ch;
}

/* USER CODE END 0 */

/**
  * @brief  The application entry point.
  * @retval int
  */
int main(void)
{
  /* MCU Configuration--------------------------------------------------------*/

  /* Reset of all peripherals, Initializes the Flash interface and the Systick. */
  HAL_Init();

  /* Configure the system clock */
  SystemClock_Config();

  /* Initialize all configured peripherals */
  MX_GPIO_Init();
  MX_ADC1_Init();
  MX_ETH_Init();
  MX_I2C1_Init();
  MX_I2C3_Init();
  MX_SPI2_Init();
  MX_SPI3_Init();
  MX_TIM2_Init();
  MX_TIM3_Init();
  MX_TIM4_Init();
  MX_TIM8_Init();
  MX_TIM9_Init();
  MX_USART1_UART_Init();
  MX_USART2_UART_Init();
  MX_TIM1_Init();
  MX_TIM5_Init();
  /* USER CODE BEGIN 2 */

  // HAL function Initializations
  HAL_TIM_PWM_Start(&htim8, TIM_CHANNEL_1);
  HAL_TIM_PWM_Start(&htim8, TIM_CHANNEL_2);
  HAL_TIM_Encoder_Start(&htim3, TIM_CHANNEL_ALL);
  HAL_TIM_Encoder_Start(&htim2, TIM_CHANNEL_ALL);
  HAL_TIM_Base_Init(&htim5);
  HAL_TIM_Base_Start_IT(&htim5);
  HAL_I2C_Init(&hi2c3);


// #################### Initializations   ####################

//  /* main code initialization

//  LRL_PID_Init(&pid_motor_left,  1);
//  LRL_PID_Init(&pid_motor_right, 1);

  HAL_GPIO_WritePin(BLINK_LED_PORT, BLINK_LED_PIN, 1);

  LRL_PID_Init(&mypid, 1);

  LRL_Odometry_Init(&odom);

  LRL_IMU_MPUInit(&imu);

  LRL_IMU_MagInit(&imu);

  LRL_ROSSerial_Init(&usb2serial_packet, USB2SERIAL_UART_HANDLER);
  LRL_ROSSerial_Init(&ros_packet, JETSON_UART_HANDLER);

  HAL_GPIO_WritePin(BLINK_LED_PORT, BLINK_LED_PIN, 0);

  odom.dist.right = 0;
  odom.dist.left = 0;

  /* USER CODE END 2 */

  /* Infinite loop */
  /* USER CODE BEGIN WHILE */
  while (1)
  {
	  if(pid_tim_flag == 1)
	  {
		 LRL_ROSSerial_Data_Handle(&ros_packet, &imu, &odom, &mypid);
		 LRL_ROSSerial_Data_Handle(&usb2serial_packet, &imu, &odom, &mypid);
		 pid_tim_flag = 0;
	  }

    /* USER CODE END WHILE */

    /* USER CODE BEGIN 3 */
  }
  /* USER CODE END 3 */
}

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
/* USER CODE BEGIN 4 */

// CRC

// ####################   Ultra Sonic Callback   ####################

/*
void HAL_TIM_IC_CaptureCallback(TIM_HandleTypeDef *htim)
{
	// TIMER Input Capture Callback
	LRL_US_TMR_IC_ISR(htim, us_front);
}
*/

// ####################   UART Receive Callback   ####################

void HAL_UART_RxCpltCallback(UART_HandleTypeDef *huart){

	if((huart == ros_packet.huart) || (huart == usb2serial_packet.huart))
	{
		LRL_ROSSerial_Rx(&ros_packet);
		LRL_ROSSerial_Rx(&usb2serial_packet);
//		HAL_GPIO_WritePin(BLINK_LED_PORT, BLINK_LED_PIN, 1); // this is for testing purposes
	}



}

// ####################   Timer To Creat 0.01 Delay Callback   ####################

void HAL_TIM_PeriodElapsedCallback(TIM_HandleTypeDef* htim){
	if(htim == &htim5)
	{
		pid_tim_flag = 1;
	}

}

// ####################   Timer Callback   ####################

/* USER CODE END 4 */
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


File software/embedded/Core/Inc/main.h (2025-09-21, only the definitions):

#define TRIG_HC_3_Pin GPIO_PIN_3
#define TRIG_HC_3_GPIO_Port GPIOE
#define TRIG_HC_4_Pin GPIO_PIN_4
#define TRIG_HC_4_GPIO_Port GPIOE
#define ECHO_HC_3_Pin GPIO_PIN_5
#define ECHO_HC_3_GPIO_Port GPIOE
#define ECHO_HC_4_Pin GPIO_PIN_6
#define ECHO_HC_4_GPIO_Port GPIOE
#define JET_SPI_MISO_Pin GPIO_PIN_2
#define JET_SPI_MISO_GPIO_Port GPIOC
#define JET_SPI_MOSI_Pin GPIO_PIN_3
#define JET_SPI_MOSI_GPIO_Port GPIOC
#define Buzzer_Pin GPIO_PIN_4
#define Buzzer_GPIO_Port GPIOA
#define Battery_ADC_Pin GPIO_PIN_5
#define Battery_ADC_GPIO_Port GPIOA
#define JET_SPI_SCK_Pin GPIO_PIN_10
#define JET_SPI_SCK_GPIO_Port GPIOB
#define MOTOR1_PWM_Pin GPIO_PIN_6
#define MOTOR1_PWM_GPIO_Port GPIOC
#define MOTOR2_PWM_Pin GPIO_PIN_7
#define MOTOR2_PWM_GPIO_Port GPIOC
#define BUS_SDA_Pin GPIO_PIN_9
#define BUS_SDA_GPIO_Port GPIOC
#define BUS_SCL_Pin GPIO_PIN_8
#define BUS_SCL_GPIO_Port GPIOA
#define USB2Serial_TX_Pin GPIO_PIN_9
#define USB2Serial_TX_GPIO_Port GPIOA
#define USB2Serial_RX_Pin GPIO_PIN_10
#define USB2Serial_RX_GPIO_Port GPIOA
#define ENCODER2_A_Pin GPIO_PIN_15
#define ENCODER2_A_GPIO_Port GPIOA
#define MOTOR2_B_Pin GPIO_PIN_0
#define MOTOR2_B_GPIO_Port GPIOD
#define MOTOR2_A_Pin GPIO_PIN_1
#define MOTOR2_A_GPIO_Port GPIOD
#define MOTOR1_B_Pin GPIO_PIN_3
#define MOTOR1_B_GPIO_Port GPIOD
#define MOTOR1_A_Pin GPIO_PIN_4
#define MOTOR1_A_GPIO_Port GPIOD
#define ENCODER2_B_Pin GPIO_PIN_3
#define ENCODER2_B_GPIO_Port GPIOB
#define ENCODER1_A_Pin GPIO_PIN_4
#define ENCODER1_A_GPIO_Port GPIOB
#define ENCODER1_B_Pin GPIO_PIN_5
#define ENCODER1_B_GPIO_Port GPIOB
#define JET_I2C_SCL_Pin GPIO_PIN_6
#define JET_I2C_SCL_GPIO_Port GPIOB
#define JET_I2C_SDA_Pin GPIO_PIN_7
#define JET_I2C_SDA_GPIO_Port GPIOB
#define ECHO_HC_1_Pin GPIO_PIN_8
#define ECHO_HC_1_GPIO_Port GPIOB
#define ECHO_HC_2_Pin GPIO_PIN_9
#define ECHO_HC_2_GPIO_Port GPIOB
#define TRIG_HC_1_Pin GPIO_PIN_0
#define TRIG_HC_1_GPIO_Port GPIOE
#define TRIG_HC_2_Pin GPIO_PIN_1
#define TRIG_HC_2_GPIO_Port GPIOE
#define rad2deg 57.2958
#define Speed2PWM_Rate 75/218
#define Tick2RMP_Rate 6000/48960

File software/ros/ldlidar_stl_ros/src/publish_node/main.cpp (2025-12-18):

/**
 * @file main.cpp
 * @author LDRobot (marketing1@ldrobot.com)
 * @brief  main process App
 *         This code is only applicable to LDROBOT LiDAR LD06 products 
 * sold by Shenzhen LDROBOT Co., LTD    
 * @version 0.1
 * @date 2021-10-28
 *
 * @copyright Copyright (c) 2021  SHENZHEN LDROBOT CO., LTD. All rights
 * reserved.
 * Licensed under the MIT License (the "License");
 * you may not use this file except in compliance with the License.
 * You may obtain a copy of the License in the file LICENSE
 * Unless required by applicable law or agreed to in writing, software
 * distributed under the License is distributed on an "AS IS" BASIS,
 * WITHOUT WARRANTIES OR CONDITIONS OF ANY KIND, either express or implied.
 * See the License for the specific language governing permissions and
 * limitations under the License.
 */
#include "ros_api.h"
#include "lipkg.h"

void  ToLaserscanMessagePublish(ldlidar::Points2D& src, ldlidar::LiPkg* commpkg, LaserScanSetting& setting, ros::Publisher& lidarpub);

int main(int argc, char **argv) {
  ros::init(argc, argv, "ldldiar_publisher");
  ros::NodeHandle nh;  // create a ROS Node
  ros::NodeHandle nh_private("~");
  std::string product_name;
	std::string topic_name;
	std::string port_name;
  LaserScanSetting setting;
	
  nh_private.getParam("product_name", product_name);
	nh_private.getParam("topic_name", topic_name);
	nh_private.getParam("port_name", port_name);
	nh_private.param("frame_id", setting.frame_id, std::string("base_laser"));
  nh_private.param("laser_scan_dir", setting.laser_scan_dir, bool(true));
  nh_private.param("enable_angle_crop_func", setting.enable_angle_crop_func, bool(false));
  nh_private.param("angle_crop_min", setting.angle_crop_min, double(0.0));
  nh_private.param("angle_crop_max", setting.angle_crop_max, double(0.0));

  ldlidar::LiPkg *lidar_commh = new ldlidar::LiPkg();
  ldlidar::CmdInterfaceLinux *cmd_port = new ldlidar::CmdInterfaceLinux();

  ROS_INFO_STREAM("[ldrobot] SDK Pack Version is: " << lidar_commh->GetSdkVersionNumber());
  ROS_INFO("[ldrobot] <product_name>: %s,<topic_name>: %s,<port_name>: %s,<frame_id>: %s", 
    product_name.c_str(), topic_name.c_str(), port_name.c_str(), setting.frame_id.c_str());

  ROS_INFO("[ldrobot] <laser_scan_dir>: %s,<enable_angle_crop_func>: %s,<angle_crop_min>: %f,<angle_crop_max>: %f",
   (setting.laser_scan_dir?"Counterclockwise":"Clockwise"), (setting.enable_angle_crop_func?"true":"false"), setting.angle_crop_min, setting.angle_crop_max);

  if (port_name.empty()) {
    ROS_ERROR("[ldrobot] input <port_name> param is null");
    exit(EXIT_FAILURE);
  }

  cmd_port->SetReadCallback(std::bind(&ldlidar::LiPkg::CommReadCallback, lidar_commh, std::placeholders::_1, std::placeholders::_2));
  
  if (cmd_port->Open(port_name)) {
    ROS_INFO("[ldrobot] open %s device %s is success", product_name.c_str(), port_name.c_str());
  }else {
    ROS_ERROR("[ldrobot] open %s device %s is fail", product_name.c_str(), port_name.c_str());
    exit(EXIT_FAILURE);
  }
  
  ros::Publisher lidar_pub = nh.advertise<sensor_msgs::LaserScan>(topic_name, 10);  // create a ROS topic
  
  ros::Rate r(10); //10hz

  auto last_time = std::chrono::steady_clock::now();

  while (ros::ok()) {
    if (lidar_commh->IsFrameReady()) {
      lidar_commh->ResetFrameReady();
      last_time = std::chrono::steady_clock::now();
      ldlidar::Points2D laserscandata = lidar_commh->GetLaserScanData();
      ToLaserscanMessagePublish(laserscandata, lidar_commh, setting, lidar_pub);
    }

    if (std::chrono::duration_cast<std::chrono::milliseconds>(std::chrono::steady_clock::now()-last_time).count() > 1000) { 
			ROS_ERROR("[ldrobot] lidar pub data is time out, please check lidar device");
			exit(EXIT_FAILURE);
		}

    r.sleep();
  }

  cmd_port->Close();
  delete lidar_commh;
  lidar_commh = nullptr;
  delete cmd_port;
  cmd_port = nullptr;
  
  return 0;
}

void  ToLaserscanMessagePublish(ldlidar::Points2D& src, ldlidar::LiPkg* commpkg, LaserScanSetting& setting, ros::Publisher& lidarpub) {
  float angle_min, angle_max, range_min, range_max, angle_increment;
  float scan_time;
  ros::Time start_scan_time;
  static ros::Time end_scan_time;

  start_scan_time = ros::Time::now();
  scan_time = (start_scan_time - end_scan_time).toSec();

  // Adjust the parameters according to the demand
  angle_min = ANGLE_TO_RADIAN(src.front().angle);
  angle_max = ANGLE_TO_RADIAN(src.back().angle);
  range_min = 0.02;
  range_max = 12;
  float spin_speed = static_cast<float>(commpkg->GetSpeedOrigin());
  float scan_freq = static_cast<float>(commpkg->kPointFrequence);
  angle_increment = ANGLE_TO_RADIAN(spin_speed/scan_freq);

  // Calculate the number of scanning points
  if (commpkg->GetSpeedOrigin() > 0) {
    int beam_size = static_cast<int>(ceil((angle_max - angle_min) / angle_increment));
    sensor_msgs::LaserScan output;
    output.header.stamp = start_scan_time;
    output.header.frame_id = setting.frame_id;
    output.angle_min = angle_min;
    output.angle_max = angle_max;
    output.range_min = range_min;
    output.range_max = range_max;
    output.angle_increment = angle_increment;
    if (beam_size <= 1) {
      output.time_increment = 0;
    } else {
      output.time_increment = scan_time / (float)(beam_size - 1);
    }
    output.scan_time = scan_time;
    // First fill all the data with Nan
    output.ranges.assign(beam_size, std::numeric_limits<float>::quiet_NaN());
    output.intensities.assign(beam_size, std::numeric_limits<float>::quiet_NaN());

    for (auto point : src) {
      float range = point.distance / 1000.f;  // distance unit transform to meters
      float intensity = point.intensity;      // laser receive intensity 
      float dir_angle = point.angle;

      if ((point.distance == 0) && (point.intensity == 0)) { // filter is handled to  0, Nan will be assigned variable.
        range = std::numeric_limits<float>::quiet_NaN(); 
        intensity = std::numeric_limits<float>::quiet_NaN();
      }

      if (setting.enable_angle_crop_func) { // Angle crop setting, Mask data within the set angle range
        if ((dir_angle >= setting.angle_crop_min) && (dir_angle <= setting.angle_crop_max)) {
          range = std::numeric_limits<float>::quiet_NaN();
          intensity = std::numeric_limits<float>::quiet_NaN();
        }
      }

      float angle = ANGLE_TO_RADIAN(dir_angle); // Lidar angle unit form degree transform to radian
      int index = (int)((angle - output.angle_min) / output.angle_increment);
      if (index < beam_size) {
        if (index < 0) {
          ROS_ERROR("[ldrobot] error index: %d, beam_size: %d, angle: %f, output.angle_min: %f, output.angle_increment: %f", index, beam_size, angle, output.angle_min, output.angle_increment);
        }
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

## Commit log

2023-08-13 [ADD] Components: Sensors, Actuators, and PCBs
    [Ball Caster 12mm.SLDPRT, Bracket-Motor.SLDPRT, JGA25-371.SLDPRT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]
2023-08-13 [ADD] a Basic Mechanical Body with Modular Features
    This commit introduces a basic illustration of a simple mechanical body design. The primary focus of this design is to provide a robust and modular framework capable of differential drive, localizati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
    Key Features:
    The base design incorporates the following essential sensors:
    - Odometry for precise motion tracking
    - Ultrasonic sensors for local distance measurement
    - LIDAR for extensive range and point cloud mapping
    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
    [Main-Chassis.SLDPRT, Middle-Chassis-Jetson.SLDPRT, Middle-Chassis-MCU.SLDPRT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]
2024-04-19 :sparkles: [EDIT] : Finalizing CAD files
    [18650-Li-Ion.SLDPRT, Abstandhalter M3 IG-AG 5mm+6mm - PA 66, schwarz.stp.SLDPRT, Antena 3 dBi 5.8 GHz v3.SLDPRT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]
2024-04-19 :sparkles: [FEATURE] : Add a class for serial frame handler and serial transmit
2024-05-18 :sparkles: [EDIT] : Add code for motion control using serial protocol
    this code uses protocol v0.0.1 to get each motor speed from the high level controller(in our case Jetson Nano SBC). the code is consisted of two main parts: motor and PID control loop, and the protoc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
    NOTE: the code only works for Motion Control i.e. set both motor speeds, for now. the address table for this is 0x01. it might change in the future
2024-05-18 :zap: [FIX] : added timeout for the RX packet function
    [packet_handler.py]
2024-05-21 :art: [EDIT] : changing gy80 name to imu for the imu struct
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2024-05-25 :sparkle: [FEATURE] : Adding reverse direction support in PID and motor codes
    [main.c, pid.c, pid.h]
2024-05-25 :sparkle: [FEATURE] : fixing the direction error
    [main.c, pid.c]
2024-06-01 🎨 [EDIT] : Improved Structure and Part Organization
    [2.4-GHz-Antenna.SLDPRT, M2.5 5mm.SLDPRT, top-plate-back.SLDPRT]
2024-06-01 🔥 [REMOVE] : Removed Old Designs
    [Battery-Knobe.SLDPRT, Main-Chassis.SLDPRT, Middle-Chassis-Jetson.SLDPRT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]
2024-06-01 📝 [DOC] : Add Robot Image to the README.md
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2024-06-01 🔥[REMOVE] : Removed STL files
    [lidar-usb2serial-holder.STL]
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2024-06-01 🎨 [EDIT] : Organize folder structure and Edit README.md
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2024-06-05 :sparkle: [FEATURE] : moving odometry functions to this repository
2024-06-05 :sparkles: [Add] : new packet handler library
    needs a major bug fix
    [Lenna-Bardia-MCU-Board.ioc, main.c, pid.c]
2024-06-08 :bug: [FIX] : put dir in the library and fix packet handler and add handshake
    [main.c, odometry.c, pid.c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]
2024-06-09 ⚡️ [EDIT] : Improved PID Controller with Direction Handler
2024-06-09 :sparkle: [FEATURE] : adding distance from encoder to odom
2024-06-10 🐛 [FIX] : Serial Packet Not Sending Wheel Speeds
    [main.c]
2024-06-10 ⚡️ [EDIT] : Improved Magnetometer Calibration and 0~360 Mapping
2024-06-10 :bug: [FIX] : correcting data send
    [main.c, odometry.c]
2024-06-24 :hammer: [FIX] : Temporary solution for UART
    [Lenna-Bardia-MCU-Board.ioc, main.c, motion.c]
2024-10-14 :sparkle: [FEATURE] : First Commit of The New Phase
    fixed an important problem with the distance calculation
    [main.c, odometry.c]
2024-11-06 :construction: [fix] : trying to handle the uncertainty in encoders
    [Lenna-Bardia-MCU-Board.ioc, odometry.c]
2024-12-25 🐛 hotfix : Motor Control Directions and Quantization Error
    [main.c, odometry.c]
2025-09-20 🔥 [REMOVE] : Deleted CAD designs! All available at LMRO-CAD
    [18650-Li-Ion.SLDPRT, 2.4-GHz-Antenna.SLDPRT, Abstandhalter M3 IG-AG 5mm+6mm - PA 66, schwarz.stp.SLDPRT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]
2025-09-20 :sparkle: [FEATURE] : subscriber script for acquiring motor velocities and their transmission through serial
2025-09-20 :fire: [REMOVE] : Remove odometry read and motor speed write test scripts
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2025-09-20 ✨ [FEATURE] : Add Lenna Description Package to ROS Workspace Inc. Lenna URDF
    [inertial_sensor_link.STL, laser_scanner_link.STL, left_wheel_link.STL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]
2025-09-20 ✨ [FEATURE] : Add ROS Control Gazebo Plugin for Continuous Joint Velocity Control
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2025-09-20 ⚡️ [ADD] : Add Gazebo Differential Drive Controller inc. Yaml and Launch files, and URDF Update
    [lenna_description.urdf]
2025-09-20 🐛 [FIX] : Remove Fixed World Link, Making The Robot to Move in Gazebo
    [lenna_description.urdf]
2025-09-20 🚧 [ADD] : Wheels' Static Transforms Declaration
    [lenna_description.urdf]
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2025-09-20 ✨ [FEATURE] : Recieve IMU Date from Serial + Publish with the Type sensor_msgs.Imu
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2025-09-20 :bug: [FIX] : default radius of wheels corrected
    [lenna_mobile_robot.py]
2025-09-20 🐛 [FIX] : Update Odometery Data Using Encoder
2025-09-20 🚑️ [FIX] : Kinematic Model Variables Fixed with Precision
    [lenna_mobile_robot.py]
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2025-09-20 ✨ [ADD] : odom_tf.py subscribe to /odom and directly publish readings to /tf
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2025-09-20 🐛 fix : edit odometery function + rectify saturation limits
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2025-09-20 🚧 ongoing : Running Navigation Stack (Odom and Scan Problem)
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2025-09-20 🐛 [FIX] : Odometery Model Orientation
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2025-09-20 :poop: this is not something good
    [actual_path.csv, actual_path_full.csv, actual_path_full_short.csv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]
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2025-09-20 🔥 [REMOVE] : Deleted Files!
    [actual_path.csv, actual_path_full.csv, actual_path_full_short.csv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]
2025-09-20 ✨ [Add] : Created lenna_bringup package containing all serial interfaces and ros pub/sub. Deleted related files from the centralized package.
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2025-09-20 ✨ [Add] : teleoperation launch file with teleop_twist_keyboard in a separated xterm window.
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2025-09-20 🎨 [edit] : fixed some naming conventions in mcu_config
    [main.h, mcu_config.h]
2025-09-21 🎨 [edit] : fixed the naming convention of the motion lib
    [motion.c]
2025-09-21 🎨 [edit] : fixed convention and minor warnings of the lib
    [main.c]
2025-09-21 🎨 [edit] : fixed naming conventions of the lib
    [main.c]
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2025-09-21 🎨 [edit] : moved imu code to the new lib
    this commit only moves the lib and does not work completely right now the next commit will fix this issue. no naming has been changed in this commit except for the Encoder -> Odometry
    [imu.c, imu.h, main.c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]
2025-09-21 🎨 [edit] : major change in naming conventions
    fixed the imu lib and moved from odometry completely
    [imu.c, imu.h, main.c]
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2025-09-21 🎨 [edit] : fixed IMU and odom commenting
    [imu.c, imu.h, odometry.c]
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2025-09-21 🚧 [Add] : Reformed the repository structure.
    Added ROS packages source codes to /software/ros.
    [inertial_sensor_link.STL, laser_scanner_link.STL, left_wheel_link.STL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]
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2025-09-21 📝 [Docs] : Added introduction and source code description of lenna_bringup package.
2025-09-21 ✨ [Add] : Latest embedded controller board software added to the new repository structure.
    Added to /software/embedded.
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2025-09-21 🔥 [Remove] : Reformed repository structure
    [inertial_sensor_link.STL, laser_scanner_link.STL, left_wheel_link.STL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]
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2025-09-25 :zap: [Edit] : Rename class to SerialHandshakeNode. Replaced 'run' method with 'handle_handshake'
    [serial_handshake_node.py]
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2025-12-11 🚧 [Fix] : Diagonal Movement and Ecludian Heurisitic
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2025-12-18 ⚡️ [ADD] : Serial Set Motor Speed TX Packet Wait Time Capability
2025-12-18 ⚡️ [EDIT] : Wait time ROS parameter for delay between TX packets
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2026-01-05 🐛 [fix] : tested and fixed the packet handler initializatoin
    [main.c]
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2026-01-07 🐛 [fix] : fixed the receiving problem
    also other types need to be checked for problems
2026-01-07 🐛 [fix] : same as packet_handler.h
2026-01-28 ❇️ [add] : added the initial stable protocol
    this code works but it is very strange that when I delete the Transmits the code stops working I should work on this
2026-01-28 🐛 [fix] : fixed the timing problem
    [rosserial.c]
2026-01-28 ✨ [feature] : no need to define uart handler in the variable
2026-01-28 🔧 [fix] : compatibility issues fixed
    [rosserial.c, rosserial.h]
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2026-02-18 ❇️ [edit] : fixed the PID to get only one handler
    [pid.c, pid.h]
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2026-07-19 ✨ feature update on main.c detailed in descriptin
    - added the LED feature to see when the mcu is ready to receive commands
    - added the feature to simultaneously receive uart on Jetson and USB2Serial
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

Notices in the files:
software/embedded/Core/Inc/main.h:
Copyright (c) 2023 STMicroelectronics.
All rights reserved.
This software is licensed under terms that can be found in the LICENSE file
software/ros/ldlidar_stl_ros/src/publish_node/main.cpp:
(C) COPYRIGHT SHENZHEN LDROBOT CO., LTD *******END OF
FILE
